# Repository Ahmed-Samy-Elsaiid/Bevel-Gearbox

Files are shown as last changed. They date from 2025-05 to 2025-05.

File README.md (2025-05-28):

# Bevel Gearbox Design Project

 


**A comprehensive design and analysis of a bevel gear transmission system developed for Mechanical Design II at Alexandria University.**

## 📌 Project Overview

This project presents a complete engineering solution for a bevel gear transmission system capable of:
- Transmitting **12.57 kW** power
- Converting **1200 rpm input** to **300 rpm output** (4:1 reduction ratio)
- Increasing torque from **100 N·m** to **400 N·m**
- Operating with **safety factors of 2.65** for both bending and contact stresses

## 🛠️ Technical Specifications

### ⚙️ Gear System
| Parameter | Pinion | Gear |
|---|---|---|
| Teeth Count | 15 | 60 |
| Pitch Diameter | 180 mm | 720 mm |
| Cone Angle | 14.04° | 75.96° |
| Module | 12 mm | 12 mm |
| Face Width | 100 mm | 100 mm |
| Pressure Angle | 20° | 20° |

### 🔩 Key Components
- **Bearings:** SKF 6210 (Dynamic load: 37.1kN, Static load: 23.2 kN)
- **Shafts:** 
  - Pinion shaft: Ø48-62mm
  - Gear shaft: Ø50-55mm
- **Seals:** Radial mechanical seals (Ø62mm)

## 📂 Repository Structure

```
Bevel-Gearbox
├── CAD
│   ├── Assembly                  # Main gearbox assembly and subassemblies
│   ├── Casing                    # Housing and structural components
│   ├── Gears                     # Bevel gear pair (pinion and wheel)
│   ├── Shafts                    # Rotating shaft components
│   ├── Keys                      # Keyways and power transmission keys
│   ├── Caps                      # Bearing caps and end covers
│   ├── Gaskets                   # Sealing interfaces
│   ├── Oil                       # Lubrication system components
│   ├── Sealing                   # Dynamic sealing elements
│   └── Drawing                   # Technical drawings (2D blueprints)
│
│── Calculations
│   └── Calculations.EES          # Engineering Equation Solver script
│
│── Documentation
│   └── Design Report.pdf         # Complete design report
│
└── README.md                     # Project documentation
```

## 🧑‍💻 Team Members

| Name                                      | 
|-------------------------------------------|
| Ahmed Samy Elsaiid Mohamed Ahmed Elshimy  | 
| Ahmed Saiid Abdelnaby Abdelrahman         |
| Ahmed Mohamed Ahmed Saleh                 | 
| Ahmed Mohamed Refaat Bassiouny            |
| Ayman Muhammad Hussien El-sayed Muhammed  | 
| Ziad Ashraf Mohamed Ali                   |
| Mohamed Ashraf Ali Mohamed                | 
| Mohamed Alaa Hassan Mabrouk               |
| Mahmoud Mohamed Abdallah Elnahas          |

## 🔍 Key Features

✅ **Precision Gear Design**  
- AGMA-compliant tooth profiles
- Optimal cone angles for perfect meshing
- 100mm face width for load distribution

✅ **Robust Mechanical Design**  
- SKF 6210 bearings for radial/axial loads
- Properly sized shafts (Von Mises criteria)
- Integrated sealing solutions

✅ **Complete Documentation**  
- 3D CAD models (SolidWorks)
- 2D manufacturing drawings (AutoCAD)
- Detailed stress analysis (AGMA standards)

## 📚 References

1. AGMA 2003-B97 - Bevel Gear Rating Standard
2. ISO 6336-1:2019 - Gear Load Capacity
3. SKF Bearing Catalogue (2022)
4. GearTrax by Camnetics

## 📄 License

Free for educational and non-commercial use. For commercial applications, please contact the author.

---

<div align="center">
  <i>Developed with ❤️ by Team 21 | Alexandria University | Mechanical Design II - Spring 2025</i>
</div>

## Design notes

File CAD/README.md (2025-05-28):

# Bevel Gearbox CAD Models



Complete CAD package for a bevel gearbox system. All files synchronized in the latest update.

## 🚀 Quick Start
1. **Download Bevel-Gearbox.zip**
2. Extract the archive
3. Open `Gear box assembly` in SolidWorks

## 📂 File Contents
| Folder | Contents |
|---|---|
| `Assembly`  | Main gearbox assembly |
| `Casing` | Housing and enclosure components  |
| `Gears` | Pinion and driven gear |
| `Shafts` | Input/output shafts |
| `Keys` | Shaft key components |
| `Caps` | End caps and covers |
| `Gaskets` | Sealing gaskets |
| `Oil` | Lubrication components |
| `Sealing` | Additional seals |
| `Drawing` | 2D technical drawings (DWG) |

## ⚠️ Important Notes
- **Requirements**: SolidWorks 2023 or compatible
- **All files updated**: 4 minutes ago
- **ZIP file contains**: Complete working assembly with all references
- **For collaborators**: Edit individual components before updating assemblies

## 🛠️ Troubleshooting
If files appear missing:
1. Always use the `Bevel-Gearbox.zip` package
2. In SolidWorks: Tools > Find References
3. Ensure all subfolders are in the same directory

## 📄 License

Free for educational and non-commercial use. For commercial applications, please contact the author.

---

<div align="center">
  <i>Developed with ❤️ by Team 21 | Alexandria University | Mechanical Design II - Spring 2025</i>
</div>

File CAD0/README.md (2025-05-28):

# Bevel Gearbox Design Project

 


A comprehensive design and analysis of a bevel gear transmission system developed for Mechanical Design II at Alexandria University.

## 📌 Project Overview

This project presents a complete engineering solution for a bevel gear transmission system capable of:
- Transmitting **12.57 kW** power
- Converting **1200 rpm input** to **300 rpm output** (4:1 reduction ratio)
- Increasing torque from **100 N·m** to **400 N·m**
- Operating with **safety factors of 2.65** for both bending and contact stresses

## 🛠️ Technical Specifications

### ⚙️ Gear System
| Parameter | Pinion | Gear |
|---|---|---|
| Teeth Count | 15 | 60 |
| Pitch Diameter | 180 mm | 720 mm |
| Cone Angle | 14.04° | 75.96° |
| Module | 12 mm | 12 mm |
| Face Width | 100 mm | 100 mm |
| Pressure Angle | 20° | 20° |

### 🔩 Key Components
- **Bearings:** SKF 6210 (Dynamic load: 37.1kN, Static load: 23.2 kN)
- **Shafts:** 
  - Pinion shaft: Ø48-62mm
  - Gear shaft: Ø50-55mm
- **Seals:** Radial mechanical seals (Ø62mm)

## 📂 Repository Structure

```
Bevel-Gearbox
│── Cad
│   ├── Assembly.SLDASM    # Complete gearbox assembly
│   ├── Pinion.SLDPRT      # Pinion 3D model
│   ├── Gear.SLDPRT        # Gear 3D model
│   └── Assembly.DWG       # 2D technical drawings
│
│── Calculations
│   └── EES_Code.EES       # Engineering Equation Solver script
│
│── Documentation
│   └── Project_Report.pdf # Complete design report
│
└── README.md              # Project documentation
```

## 🧑‍💻 Team Members

| Name                                      | 
|-------------------------------------------|
| Ahmed Samy Elsaiid Mohamed Ahmed Elshimy  | 
| Ahmed Saiid Abdelnaby Abdelrahman         |
| Ahmed Mohamed Ahmed Saleh                 | 
| Ahmed Mohamed Refaat Bassiouny            |
| Ayman Muhammad Hussien El-sayed Muhammed  | 
| Ziad Ashraf Mohamed Ali                   |
| Mohamed Ashraf Ali Mohamed                | 
| Mohamed Alaa Hassan Mabrouk               |
| Mahmoud Mohamed Abdallah Elnahas          |

## 🔍 Key Features

✅ **Precision Gear Design**  
- AGMA-compliant tooth profiles
- Optimal cone angles for perfect meshing
- 100mm face width for load distribution

✅ **Robust Mechanical Design**  
- SKF 6210 bearings for radial/axial loads
- Properly sized shafts (Von Mises criteria)
- Integrated sealing solutions

✅ **Complete Documentation**  
- 3D CAD models (SolidWorks)
- 2D manufacturing drawings (AutoCAD)
- Detailed stress analysis (AGMA standards)

## 📚 References

1. AGMA 2003-B97 - Bevel Gear Rating Standard
2. ISO 6336-1:2019 - Gear Load Capacity
3. SKF Bearing Catalogue (2022)
4. GearTrax by Camnetics

---

<div align="center">
  <i>Developed with ❤️ by Team 21 | Alexandria University | Mechanical Design II - Spring 2025</i>
</div>

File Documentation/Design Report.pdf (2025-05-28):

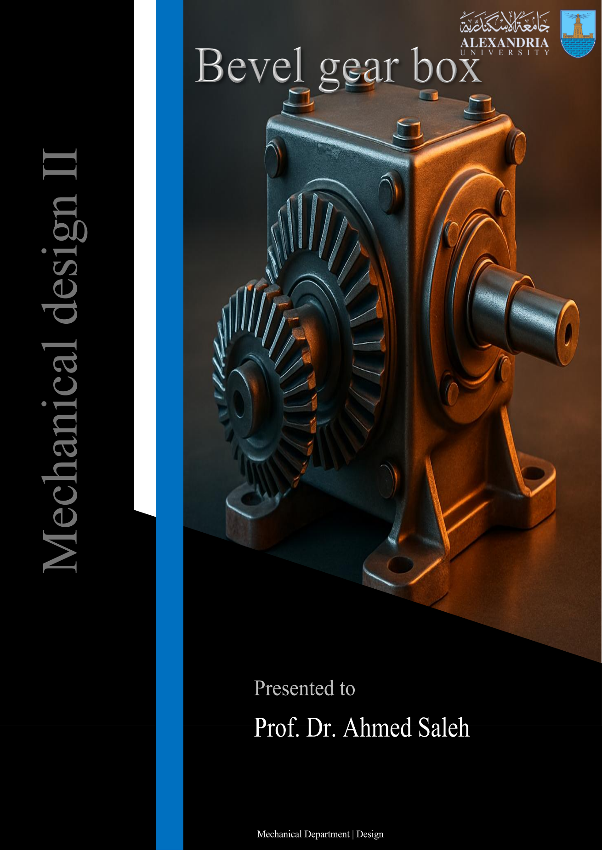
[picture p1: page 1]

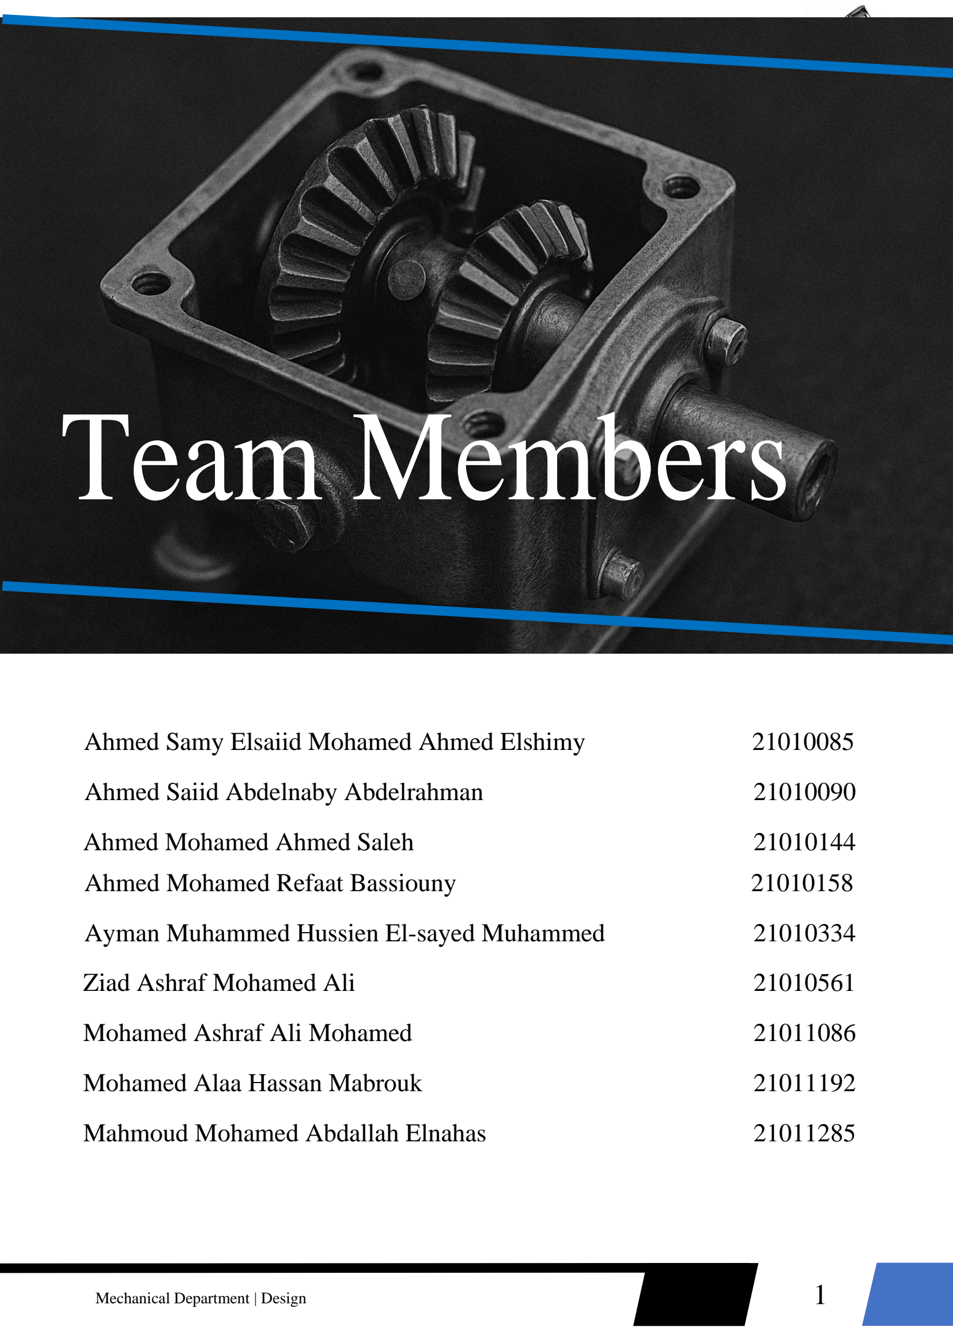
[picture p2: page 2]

Mechanical Department | Design
Ahmed Samy Elsaiid Mohamed Ahmed Elshimy | 21010085
Ahmed Saiid Abdelnaby Abdelrahman | 21010090
Ahmed Mohamed Ahmed Saleh | 21010144
Ahmed Mohamed Refaat Bassiouny | 21010158
Ayman Muhammed Hussien El-sayed Muhammed | 21010334
Ziad Ashraf Mohamed Ali | 21010561
Mohamed Ashraf Ali Mohamed | 21011086
Mohamed Alaa Hassan Mabrouk | 21011192
Mahmoud Mohamed Abdallah Elnahas | 21011285

# Team Members

# Contents

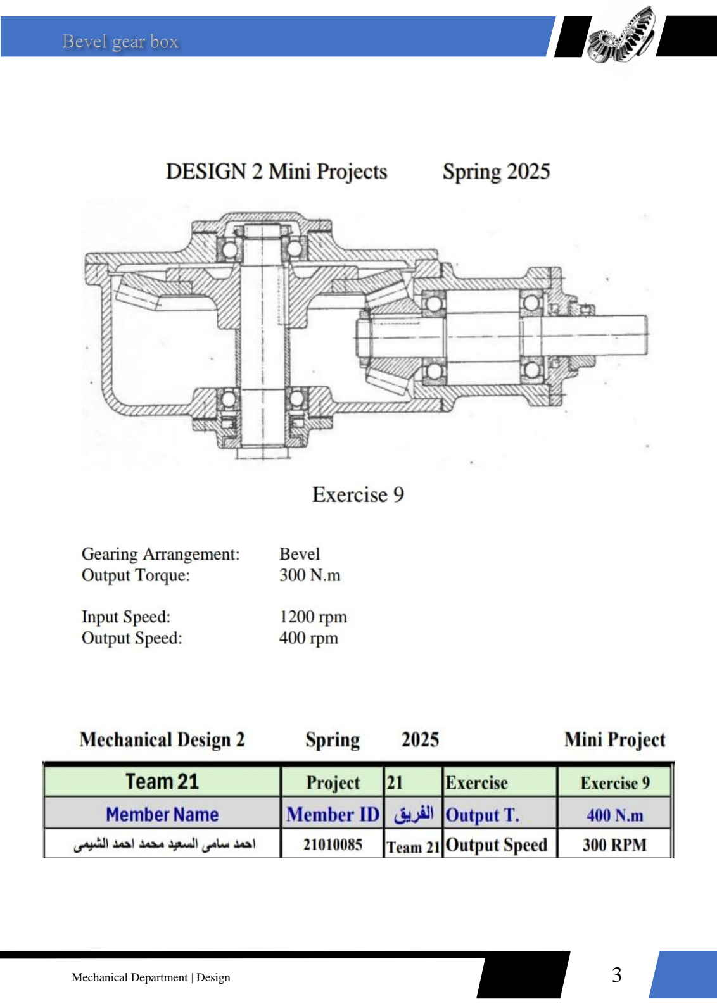
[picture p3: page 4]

## Abstract

This technical report presents a comprehensive design and engineering analysis of a bevel gear transmission system developed for efficient power transfer between intersecting shafts. The study focuses on creating an optimal gear pair configuration capable of transmitting 12.57 kW of power while converting an input speed of 1200 rpm (125.66 rad/s) to an output speed of 300 rpm (31.42 rad/s), with a corresponding torque increase from 100 N·m to 400 N·m through a 4:1 reduction ratio.

The research methodology incorporates a rigorous multi-stage engineering approach, beginning with fundamental kinematic calculations to verify speed and torque requirements. Detailed geometric design parameters are then established, including module selection (12 mm), tooth counts (15 teeth for pinion, 60 for gear), and precise pitch diameter determinations (180 mm and 720 mm respectively). The conical geometry of the bevel gears is carefully analyzed, with pinion and gear cone angles calculated at 14.04° and 75.96° to ensure proper meshing alignment.

A comprehensive force analysis forms a critical component of the study, systematically evaluating the three-dimensional loading conditions on the gear teeth. This includes calculation of tangential (1284.14 N), radial (453.43 N pinion/113.36 N gear), and axial (113.36 N pinion/453.43 N gear) force components, which are essential for subsequent shaft and bearing design considerations. The stress analysis employs American Gear Manufacturers Association (AGMA) standards to verify tooth strength under both bending and contact fatigue conditions, with particular attention to load distribution factors and dynamic effects.

The computer-aided design component utilizes industry-standard SolidWorks software for precise 3D modeling of all system components, including detailed gear tooth profiles and assembly relationships. Complementary 2D technical drawings produced in AutoCAD provide complete manufacturing specifications, incorporating geometric dimensioning and tolerancing (GD&T) standards. The integrated design approach ensures proper meshing characteristics while maintaining manufacturability requirements.

Results demonstrate a fully engineered bevel gear transmission system meeting all specified performance criteria while maintaining appropriate safety margins. The complete design package includes detailed gear geometry, force analysis data, and manufacturing documentation, providing a comprehensive solution for power transmission applications requiring shaft angle redirection. This study serves as a valuable reference for mechanical engineers designing similar bevel gear systems, offering both theoretical foundations and practical implementation guidance.

## Introduction

Bevel gears are fundamental components in mechanical power transmission systems where torque must be transferred between intersecting shafts, typically at 90 degrees. Their conical geometry allows efficient power transmission while accommodating angular misalignment. This report presents a comprehensive design and analysis of a bevel gear system based on specified operational requirements, including torque, speed, and power transmission efficiency.

## Objectives

The primary objectives of this study are:
1. To design a bevel gear pair with a 4:1 gear ratio, ensuring proper speed reduction from 1200 rpm (input) to 300 rpm (output) while increasing torque from 100 N·m to 400 N·m.
2. To perform force and stress analysis to validate gear tooth strength and durability.
3. To conduct shaft design calculations considering combined bending and torsional stresses.
4. To evaluate safety factors using AGMA (American Gear Manufacturers Association) standards for bending and contact stresses.

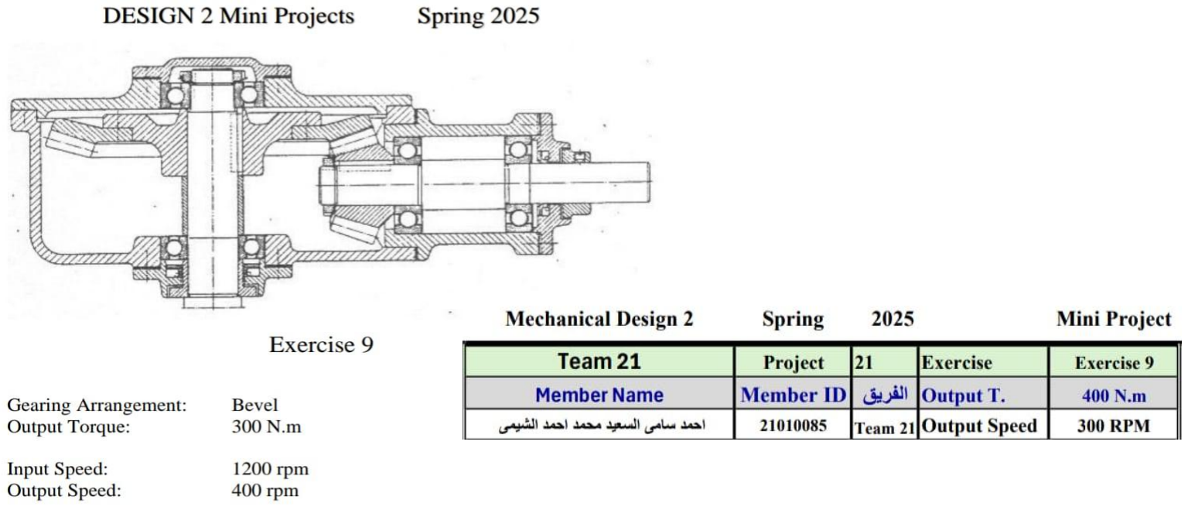
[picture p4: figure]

## Methodology

The design and analysis of the bevel gear transmission system followed a structured methodology, integrating theoretical calculations, computer-aided design (CAD), and validation techniques. The approach ensured a systematic evaluation of gear geometry, stress analysis, and manufacturability. The key stages of the methodology are outlined below.

## Design Calculations

The analytical phase involved determining critical parameters to meet performance requirements:
- Gear Ratio & Kinematics: Calculated input/output speeds and torque multiplication.
- Tooth Geometry: Determined module, pitch diameters, and cone angles based on AGMA standards.
- Force Analysis: Evaluated tangential, radial, and axial forces acting on gear teeth.
- Stress Analysis: Applied AGMA equations to assess bending and contact stresses.
- Safety Factors: Verified design reliability under operational loads.

## Computer-Aided Design (CAD)

The gear system was modeled using industry-standard CAD software to validate geometry and assembly:

- SolidWorks:
- Created 3D parametric models of the pinion and gear.
- Simulated gear meshing and interference checks.
- Generated technical drawings with tolerances and annotations.
- AutoCAD:
- Produced 2D manufacturing drawings with detailed sectional views.
- Specified key dimensions, surface finishes, and GD&T (Geometric Dimensioning & Tolerancing).

## Design Calculations

The design process follows a systematic approach:

1. Kinematic Analysis: Calculation of gear ratio, angular velocities, and power transmission.
2. Geometric Design: Determination of module, pitch diameters, and tooth geometry.
3. Force Analysis: Computation of tangential, radial, and axial forces acting on gear teeth.
4. Stress Analysis: Application of AGMA equations to assess bending and contact stresses.
5. Shaft Design: Determination of minimum shaft diameter based on combined loading conditions.

## Kinematic and Power Analysis

The power transmission system operates under the following conditions:

Parameter | Pinion | Gear
Speed (rpm) | 1200 | 300
Angular velocity (rad/s) | 125.66 | 31.42
Torque (N·m) | 100 | 400
Power (kW) | 12.566 | 12.566

The power transmission remains constant (neglecting losses), satisfying the fundamental relationship: P = T × ω = Constant
where:
- P = Power (W)
- T = Torque (N · m)
- ω = Angular velocity (rad/s)

## Geometric Design Specifications

Gear Parameters

Design Parameter | Value
Gear ratio (mG) | 04:01
Module (m) | 12 mm
Pinion teeth (Np) | 15
Gear teeth (Ng) | 60
Pressure angle (φ) | 20°
Face width (b) | 100 mm

Pitch Geometry

1. Pinion Pitch Diameter (dₚ): dp = Np × m = 15 × 12 = 180 mm
2. Gear Pitch Diameter (dg): dg = Ng × m = 60 × 12 = 720 mm
3. Pinion Cone Angle (γₚ): γp = tan⁻¹
(

Ng
Np

) = tan − 1(6015) = 14.04°

4. Gear Cone Angle (γg):
γg = 90° − γp = 90° − 14.04° = 75.96°
5. Average Diameter (dₐᵥ):
- For pinion:
davpinion = dp − b ∗ cosγp = 180 − 100 ∗ cos(14.04°) = 155.75 mm
- For gear:
davgear = dg − b ∗ cosγg = 720 − 100 ∗ cos(75.96°) = 622.99 mm

## Force Analysis

The forces acting on the gear teeth are critical for shaft and bearing design:

Force Component | Pinion (N) | Gear (N)
Tangential (Wt ) | 1284.14 | 1284.14
Radial (Wr ) | 453.43 | 113.36
Axial (Wa) | 113.36 | 453.43

Force Equations

- Tangential Force:
Wt = dav ∗ 2T
- Radial Force:
Wr = Wt
∗ tanφ ∗ cosγ
- Axial Force:
Wa = Wt
∗ tanφ ∗ sinγ

## AGMA Stress Analysis

Bending Stress (σF)
σF = bmWt

KAKv

′YxKH

YBYJ1
Where:
- KA = 1.35 (Ligℎt sℎock)
- Kv

′ = 1.5 (Quality factor Qv = 7)
- Yx = 0.5868 (Size factor)
- KH = 1.156 (Load distribution factor)
- YJ = 0.23 (Geometry factor)

Contact Stress (σH)

σH = ZE (

Wt
bdpZL

KAKv

′ZxZxc)

1
2

Where:
- ZE = 190MPa (Steel)
- Zx = 0.9295 (Mesℎ alignment factor)

Safety Factors
- Bending Safety Factor (SF):
SF =

σF

σFP
- Contact Safety Factor (SH): SH =

σH

σHP

## Shaft Design

The shaft must withstand combined bending and torsional stresses. Using von Mises theory:

d

3 =

16

π τall √(Kb Mb +
αFad
8

)

2
+ (Kt Mt

)

2

Where:

- τall = 47.5 Mpa
- Kb = 2 & Kt = 1.5

## Bearing Selection

Once the shaft design was finalized and the reaction forces at each bearing location were calculated, the next step was to select suitable bearings that can withstand the applied radial and axial loads while ensuring reliability and longevity.
The primary criteria for bearing selection included:
a. Load carrying capacity (both radial and axial),
b. Rotational speed,
c. Operating life,
d. Ease of installation and availability.

Based on the calculated reaction forces at the shaft supports (as shown in the previous section), and considering the moderate speed and load conditions in our application, we chose to use deep groove ball bearings, which are well-suited for handling radial loads and moderate axial loads with relatively low friction.
Selected Bearing: SKF 6210
We selected the SKF 6210 bearing for both the pinion and gear shafts. This offers the following advantages:
- High radial load capacity, which matches the calculated forces in our system,
- Moderate axial load capability, suitable for the axial components generated by the bevel gear interaction,
- Rated for high-speed applications, aligning with our gearbox’s operating conditions,
- Standard dimensions, making it easy to integrate into our shaft design.
- SKF 6210 specifications:
- Bore diameter: 50 mm
- Outside diameter: 90 mm
- Width: 20 mm
- Dynamic load rating (C): 37.1kN
- Static load rating (C₀): 23.2 kN
- Maximum speed: up to 7,500 rpm (depending on lubrication)

This bearing was chosen for its balance between load capacity, speed, and availability, ensuring reliable performance in our gearbox design.

The following script is written in Engineering Equation Solver (EES) and is used to analyze and design a bevel gear transmission system. The code defines all relevant input parameters, assumptions, and material properties, and performs detailed calculations for gear geometry, tangential loads, AGMA-based bending and wear stress analysis, shaft torque and moment evaluation, shaft diameter sizing under combined loading, and bearing reaction forces. The solution is automated using EES to ensure accuracy, flexibility in parameter variation, and to support design decisions in accordance with standard mechanical design practices.

## EES Code

{Givens}

T_out = 400
N_in = 1200 / 60
N_out = 300 / 60

{Assumptions}

b = 100

S_F = 2.65
S_H = 2.65
m = 12
n_p = 15
n_g = 4 * n_p
H_p = 240
H_g = 200
phi = 20
gamma = arctan(n_g / n_p)
L_p = 10 ^ 8
L_g = L_p / 4

{Precalculations}

d_p = m * n_p
d_g = m * n_g
P_w = T_out * N_out * 2 * pi
v = pi * d_p * N_in /1000
W|t = P_w / v
d_av_p = d_p - b * cos(gamma) d_av_g = d_g - b * sin(gamma)

{Bending based}

k_a = 1
k_v = 1.3
Y_x = 0.4867 + 0.008339 * m k_mb = 1.1
k_H = k_mb + 5.6 * b ^ 2 * 10 ^ (-6) Y_b = 1
Y_j_p = 0.24
Y_j_g = 0.18
sigma_F_p = W|t * k_a * k_v * y_x * k_h / (b * m * Y_b * Y_j_p) sigma_F_g = W|t * k_a * k_v * y_x * k_h / (b * m * Y_b * Y_j_g) sigma_F_lim_p = 0.3 * H_p + 14.48
sigma_F_lim_g = 0.3 * H_g + 14.48
Y_NT_p = 1.3558 * L_P ^ (-0.0178)

Y_NT_g = 1.3558 * L_g ^ (-0.0178)
K_theta = 1
Y_z = 1
sigma_FP_P = sigma_F_lim_p * Y_NT_p / (K_theta * Y_z) sigma_FP_g = sigma_F_lim_g * Y_NT_g / (K_theta * Y_z)

{S_F = sigma_FP_g / sigma_F_g}
{S_F = sigma_FP_p / sigma_F_p}

S_F_p = sigma_FP_g / sigma_F_g S_F_g = sigma_FP_p / sigma_F_p

{Wear based}

Z_E = 190
Z_x = 0.00492 * b + 0.4375
Z_xc = 2
Z_i = 0.078
sigma_H = Z_E * (W|t * k_a * k_v * k_h * z_x * z_xc / (b * d_p * z_i)) ^ (0.5) sigma_H_lim_p = 2.35 * H_p + 162.89
sigma_H_lim_g = 2.35 * H_g + 162.89
Z_NT_p = 3.4822 * L_p ^ (-0.0602)
Z_NT_g = 3.4822 * L_g ^ (-0.0602) Z_w_p = 1
Z_w_g = 1.01
K_z = Y_z
sigma_HP_P = sigma_H_lim_p * Z_NT_p * Z_W_p / (K_theta * k_z) sigma_HP_g = sigma_H_lim_g * Z_NT_g * Z_w_g / (K_theta * k_z)

{S_H = sigma_HP_P / sigma_H}
{S_H = sigma_HP_g / sigma_H}

S_H_p = sigma_HP_P / sigma_H
S_H_g = sigma_HP_g / sigma_H

{Forces, torques, and moments on pinion}

F_t_p = W|t * d_p / d_av_p
F_a_p = F_t_p * tan(phi) * cos (gamma) F_r_p = F_t_p * tan(phi) * sin (gamma) F_tr_p = (F_t_p ^ 2 + F_r_p ^2 ) ^ (0.5) L_tr_p = 70 + 20
M_t_p = (F_t_p + W_p) * L_tr_p M_a_p = F_a_p * d_av_p / 2
M_r_p = F_r_p * L_tr_p
M_ra_p = M_r_p - M_a_p
M_p = (M_t_p ^ 2 + M_ra_p ^2) ^ (0.5) T_p = F_t_p * d_av_p / 2

{Bearing reactions for pinion shaft}

L_B_p = 100
W_p = 17 *9.81
B_n_t_p = (F_t_p + W_p) * (L_tr_p + L_B_p) / L_B_p B_n_a_p = M_a_p / L_B_p
B_n_r_p = F_r_p * (L_tr_p + L_B_p) / L_B_p B_n_ra_p = B_n_r_p - B_n_a_p
B_n_p = (B_n_t_p ^ 2 + B_n_ra_p ^2) ^ (0.5) B_f_p = M_p / L_B_p

{Shaft design for pinion}

k_b = 1.5
k_t = 1
S_y = 380
{F_s_p = 3}
d_sh_p = 48
d_sh_u_p = d_sh_p - 1
tau_all_p = S_y * 0.75 *0.5 / F_s_p
alpha_p = 1 / (1 - 0.0044 * (4 * (L_tr_p + L_B_p) / d_sh_u_p))
d_sh_u_p = (16 / (pi * tau_all_p) * ((k_b * M_p + alpha_p * f_a_p * d_sh_u_p / 8) ^ 2 + (k_t * T_p) ^ 2) ^ (0.5)) ^ (1 / 3)

{Forces, torques, and moments on gear}

F_t_g = F_t_p
F_a_g = F_r_p
F_r_g = F_a_p
L_tr_g = 80 + 20
F_tr_g = (F_t_g ^ 2 + F_r_g ^2 ) ^ (0.5) M_t_g = F_t_g * L_tr_g
M_a_g = F_a_g * d_av_g / 2
M_r_g = F_r_g * L_tr_g
M_ra_g = M_r_g - M_a_g
M_g = B_f_g * (L_B_g - L_tr_g) T_g = T_p * N_g / N_p

{Bearing reactions for gear shaft}

L_B_g = 300
w_gk = (103 + 27.5) * 9.81
B_n_t_g = (F_t_g + W_gk) * (L_B_g - L_tr_g) / L_B_g B_n_a_g = M_a_g / L_B_g
B_n_r_g = F_r_g * (L_B_g - L_tr_g) / L_B_g B_n_ra_g = B_n_r_g - B_n_a_g
B_n_g = (B_n_t_g ^ 2 + B_n_ra_g ^2) ^ (0.5) B_f_t_g = (F_t_g + W_gk) * (L_tr_g) / L_B_g B_f_a_g = M_a_g / L_B_g
B_f_r_g = F_r_g * (L_tr_g) / L_B_g B_f_ra_g = B_f_r_g + B_f_a_g

B_f_g = (B_f_t_g ^ 2 + B_f_ra_g ^2) ^ (0.5)

{Shaft design for gear}

{F_s_g = 3}
d_sh_g = 62
tau_all_g = S_y * 0.75 *0.5 / F_s_g
alpha_g = 1 / (1 - 0.0044 * (4 * (L_tr_g + L_B_g) / d_sh_g))
d_sh_g = (16 / (pi * tau_all_g) * ((k_b * M_g + alpha_g * f_a_g * d_sh_g / 8) ^ 2 + (k_t * T_g) ^ 2) ^ (0.5)) ^ (1 / 3)

{Bearing selection}

{basic static load}
{Fa/Fr<0.8 ... Xo=1,Yo=0}

xo=1
yo=0

{normal condition}

Fs=1.2
Po= xo*B_n_p + yo*F_a_p
Co= Fs*Po

{SKF 6210, co=23.2, c=37.1} {basic dynamic load}
{fo*Fa/co=0.1104 < e=0.17932}

x=1
y=0
{uniform load}
Ks=1
{inner ring rotation}
vo=1
{basic rating life}
L=360
P=x*vo*B_n_p+y*F_a_p
C=Ks*P*(L)^(1/3)

## Computer-Aided Design (CAD)

After completing the analytical calculations and determining the required forces, torques, and dimensions for the system components, we proceeded to the mechanical design phase. This phase is essential for transforming theoretical data into a functional and manufacturable 3D model.
Using SolidWorks, we modeled each individual part of the system with precise dimensions derived from our calculations. The design ensures mechanical compatibility, proper alignment, and load distribution among gears, shafts, and bearings.
In the following section, each part is presented with its:
- Name
- Dimensions
- Material
- Function in the assembly

This step bridges the gap between theoretical engineering principles and practical implementation, ensuring that each component meets the mechanical and operational requirements of the system.

## Gear Modeling Using GearTrax

To ensure high accuracy and compliance with gear design standards, the bevel gears were modeled using GearTrax by Camnetics, a specialized add-in for SolidWorks. This tool provides a robust and precise method for generating 3D gear geometry based on input parameters such as:

- Number of teeth
- Pressure angle
- Module or diametral pitch
- Gear ratio
- Shaft angle (typically 90° for bevel gears)

Using GearTrax allowed us to automatically generate the correct tooth profile and gear geometry according to AGMA standards, which significantly improved the quality and reliability of the gear design. The resulting models were seamlessly integrated into the SolidWorks assembly, ensuring accurate alignment and meshing between the pinion and the driven gear.
This approach minimized manual modeling errors and accelerated the design process while maintaining mechanical accuracy and consistency.

### Gear 1 (Pinion):

- Number of teeth: 15
- Pitch diameter: 180 mm
- Pressure angle: 20°
- Cone Angle (γ): 14.04°
- Face width: 100mm

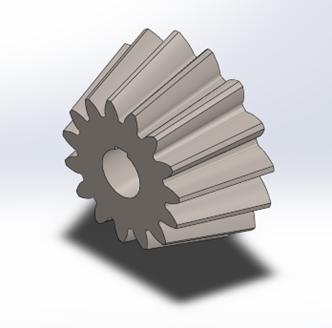
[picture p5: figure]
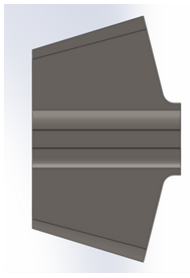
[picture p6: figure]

### Gear 2 (Gear):

- Number of teeth: 60
- Pitch diameter: 720 mm
- Pressure angle: 20°
- Cone Angle (γ): 75.96°
- Face width: 100mm

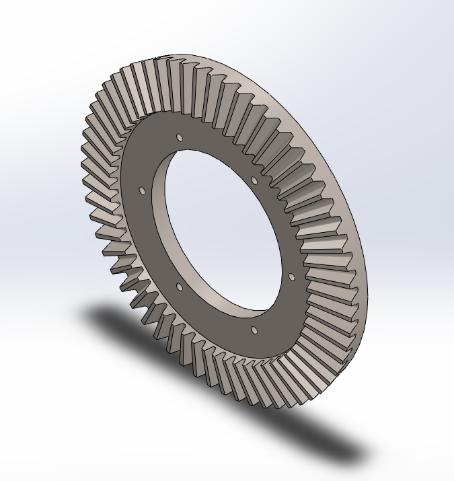
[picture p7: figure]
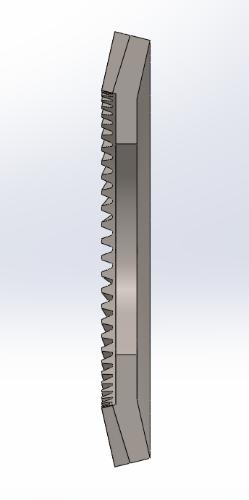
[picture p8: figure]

## Gasket Set for Bevel Gearbox Assembly

To ensure effective sealing and maintain pressure integrity within the gearbox, four custom-designed flat gaskets were modeled and integrated into the assembly. These gaskets serve to prevent lubricant leakage and protect internal components from external contaminants. All gaskets were designed in accordance with the mating flange profiles in SolidWorks, using precise cutout geometry and bolt hole alignment for seamless installation. Manufactured from 3 mm thick compressed fiber material, they offer high resistance to oil, temperature, and mechanical deformation, making them ideal for use in gear-driven power transmission systems.

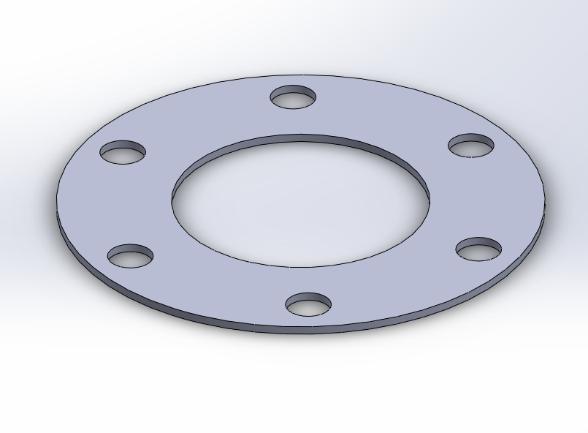
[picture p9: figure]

Gasket 1:
- Use: Sealing interface between shaft housing, gearbox casing (inlet and outlet sides) and sealing interface for the shaft support flange
- Dimensions:
- Outer diameter: 170 mm
- Inner cutout: 90 mm
- Thickness: 3 mm
- Bolt PCD: 140 mm
- Quantity: 3 identical gaskets (inlet + outlet)

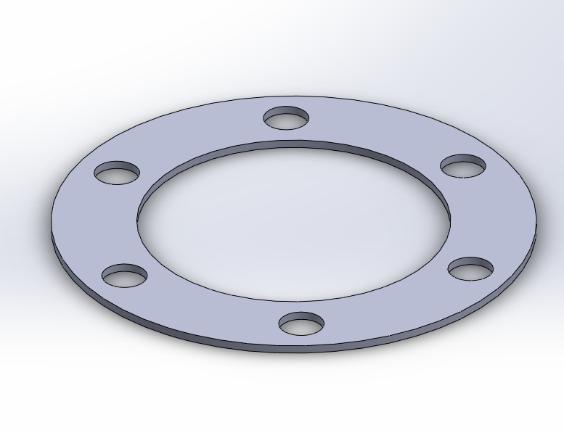
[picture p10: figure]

Gasket 2:
- Use: Between small support case and gearbox wall
- Dimensions:
- Outer diameter: 170 mm
- Inner cutout: 110 mm
- Thickness: 3 mm
- Bolt PCD: 140 mm

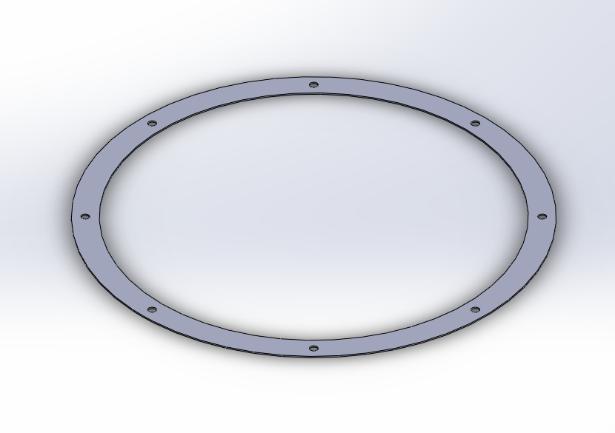
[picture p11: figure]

Gasket 3:
- Use: Sealing between the main gearbox housing and support structure
- Dimensions:
- Outer diameter: 870 mm
- Inner cutout: 770 mm
- Thickness: 3 mm
- Bolt PCD: 820 mm

## Cap Components for Bevel Gearbox Assembly

To ensure proper enclosure, shaft alignment, and mechanical protection, three distinct cap configurations were integrated into the bevel gearbox assembly. Each cap was modeled in SolidWorks with precision bolt patterns and center bore profiles to ensure compatibility with mating shafts, housings, and gaskets. The designs incorporate flat-faced surfaces and mounting flanges, simplifying installation and minimizing vibration-induced wear. All caps are assumed to be manufactured from mild steel unless otherwise specified, offering excellent machinability and structural integrity.

Cap 1:
- Function: Fully encloses the large side of the gearbox casing
- Dimensions:
- Outer diameter: 870 mm
- Boss height: 90 mm
- Pitch Circle Diameter (PCD): 820 mm
- Features: Includes a central hub with through-hole for optional alignment pin or shaft stub, and bolt holes along the outer edge for secure sealing
- Mounted with: Gasket (870×770×3, PCD: 820 mm)

Cap 2:

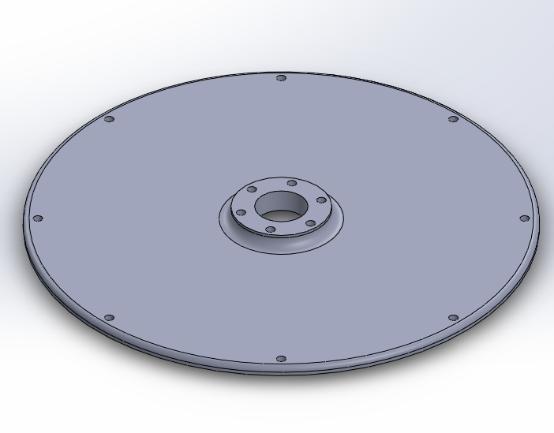
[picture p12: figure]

- Function: Closes and centers the shaft inlet region while allowing shaft clearance
- Dimensions:
- Outer diameter: 170 mm
- Boss height: 0 mm
- Pitch Circle Diameter (PCD): 140 mm
- Features: Flat design for flush mounting against shaft inlet housing; central hole accommodates shaft passage
- Mounted with: Gasket (170×90×3, PCD: 140 mm)

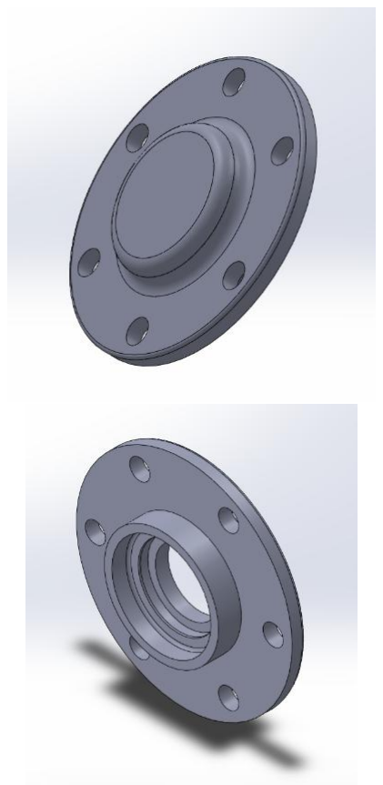
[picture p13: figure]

Cap 3:
- Function: Closes and centers the shaft outlet while providing axial spacing
- Dimensions:
- Outer diameter: 170 mm
- Boss height: 50.1 mm
- Pitch Circle Diameter (PCD): 140 mm
- Features: Raised boss ensures proper axial positioning and alignment for the output shaft; bolt holes are evenly spaced for stable fastening
- Mounted with: Gasket (170×90×3, PCD: 140 mm)

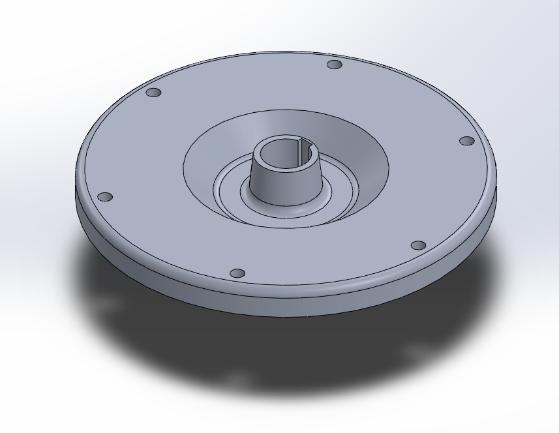
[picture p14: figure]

## Gear Mounting Kit

- Function: Secures the pinion to the input shaft with anti-rotation and axial retention.
- Dimensions:
- Outer diameter:450 mm
- Boss height: 50 mm
- Pitch Circle Diameter (PCD): 400 mm

## Gearbox Cases (Housings) – General Overview

Gearbox cases (or housings) are structural enclosures that serve as the foundation for gear systems, providing:
1. Alignment: Precise positioning of gears, shafts, and bearings.
2. Protection: Shielding internal components from contaminants (dust, moisture) and mechanical damage.
3. Lubrication Management: Contain oil/grease and facilitate cooling.
4. Load Distribution: Absorb and transmit operational forces (torque, vibrations).

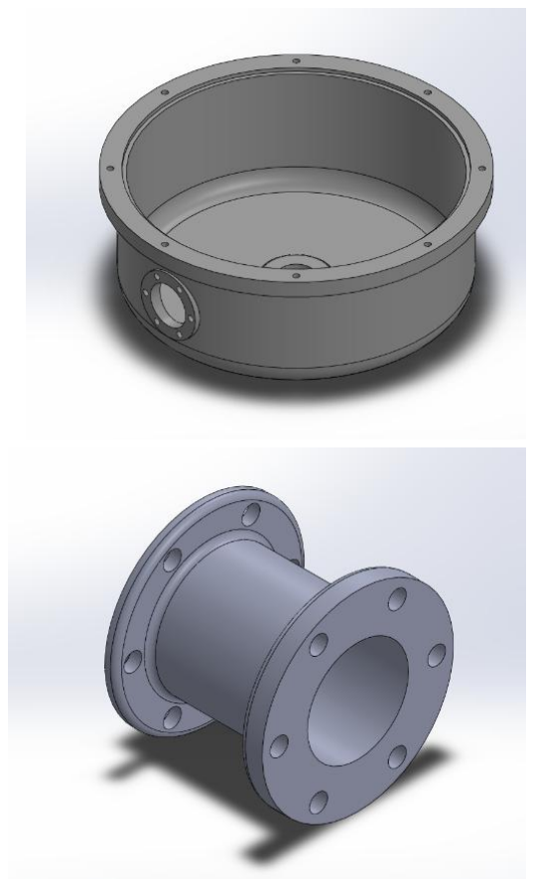
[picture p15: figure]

Big Case
- Function: The main housing encloses and
supports the large bevel gear and output shaft, providing structural rigidity, bearing alignment, and lubrication containment while handling high torque and radial loads.
- Dimensions:
- Outer diameter: 870 mm
- Boss height: 750 mm
- Pitch Circle Diameter (PCD): 820 mm

Small Case
- Function: The pinion housing secures and aligns the input shaft and bearings, ensuring precise gear meshing and sealing against lubricant leaks and contaminants.
- Dimensions:
- Outer diameter: 170 mm
- Boss height: 90 mm
- Pitch Circle Diameter (PCD): 140 mm

## Keys

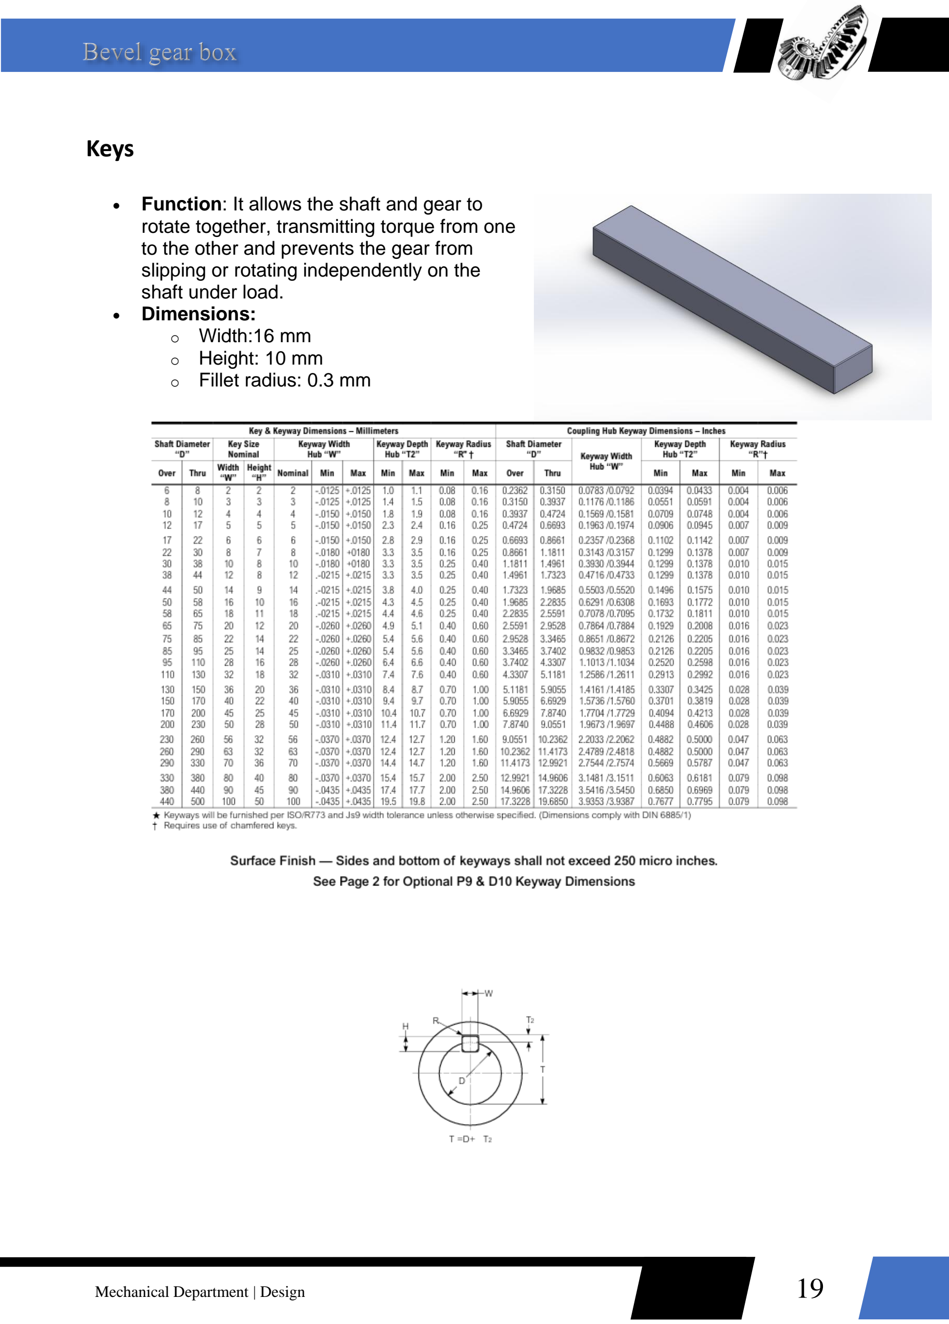
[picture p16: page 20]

- Function: It allows the shaft and gear to rotate together, transmitting torque from one to the other and prevents the gear from slipping or rotating independently on the shaft under load.
- Dimensions:
- Width:16 mm
- Height: 10 mm
- Fillet radius: 0.3 mm

## Radial Sealing

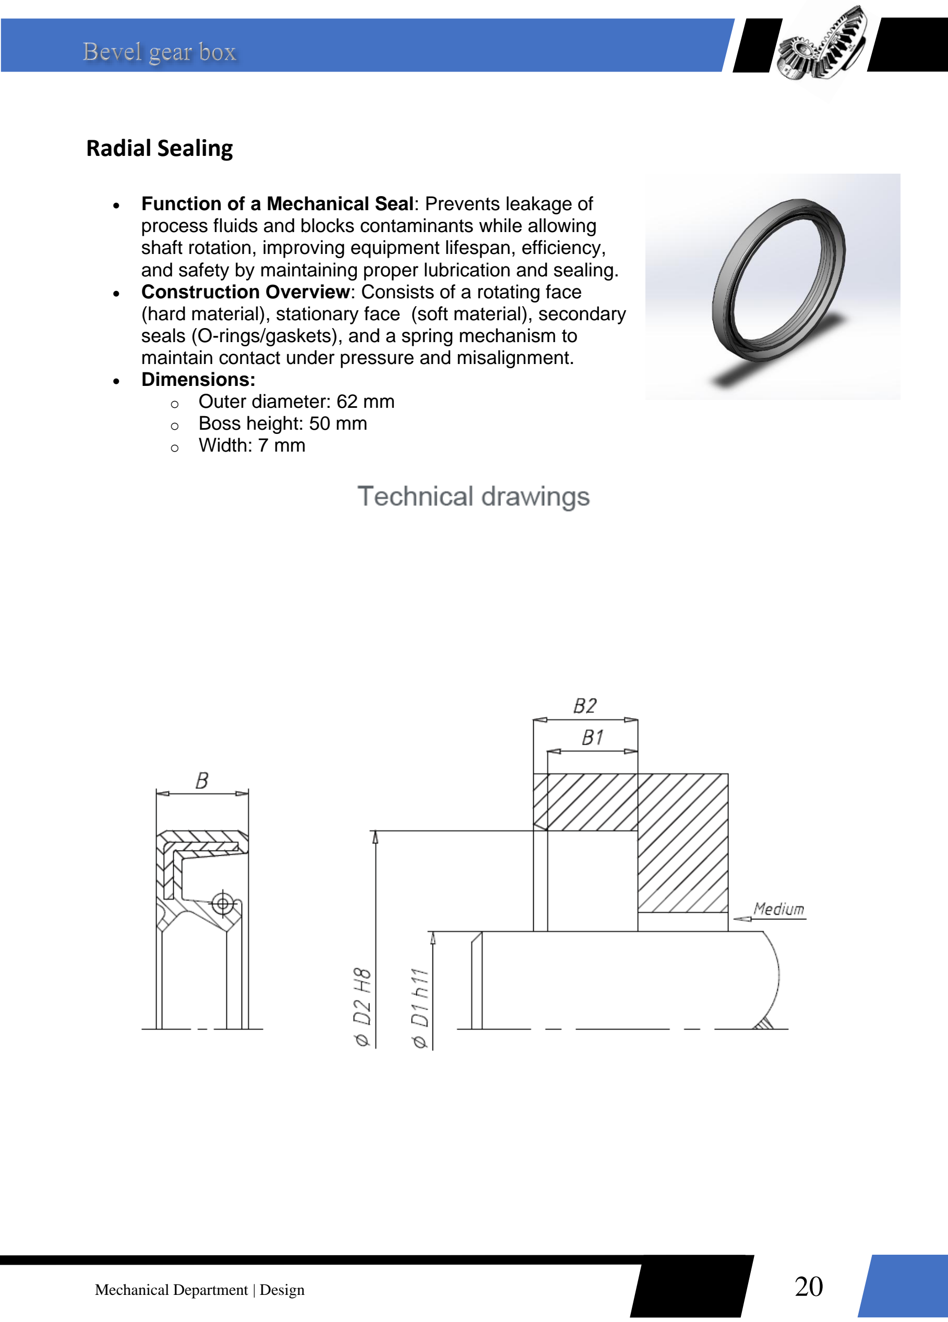
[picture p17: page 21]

- Function of a Mechanical Seal: Prevents leakage of process fluids and blocks contaminants while allowing shaft rotation, improving equipment lifespan, efficiency, and safety by maintaining proper lubrication and sealing.
- Construction Overview: Consists of a rotating face (hard material), stationary face (soft material), secondary seals (O-rings/gaskets), and a spring mechanism to maintain contact under pressure and misalignment.
- Dimensions:
- Outer diameter: 62 mm
- Boss height: 50 mm
- Width: 7 mm

## Shafts

The shaft serves as the backbone of mechanical systems, primarily transmitting torque and rotational motion between components like motors, gears, and couplings. It provides a mounting surface for critical elements such as bearings, pulleys, and seals, with features like keyways ensuring secure torque transfer via keys. Designed to withstand bending and torsional stresses, the shaft’s stepped shoulders and grooves facilitate precise bearing placement for axial and radial support, while its dimensions (diameter, length, and tolerances) dictate load capacity, alignment, and compatibility with mating parts.

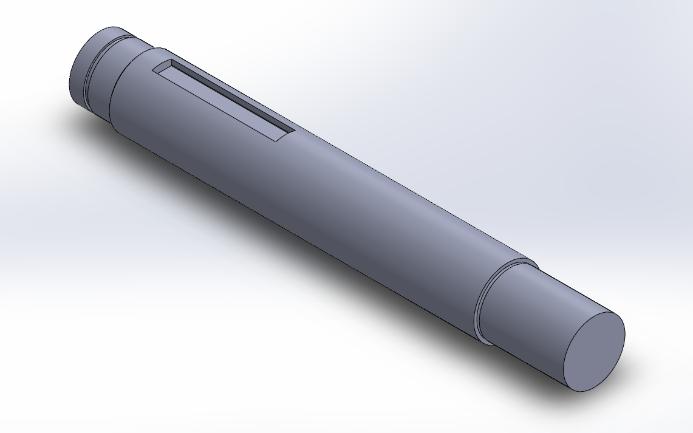
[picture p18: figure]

Gear shaft:

- Function: Drive the motion to the gear.
- Dimensions:
- Minor diameter: 50 mm
- Major diameter: 55 mm

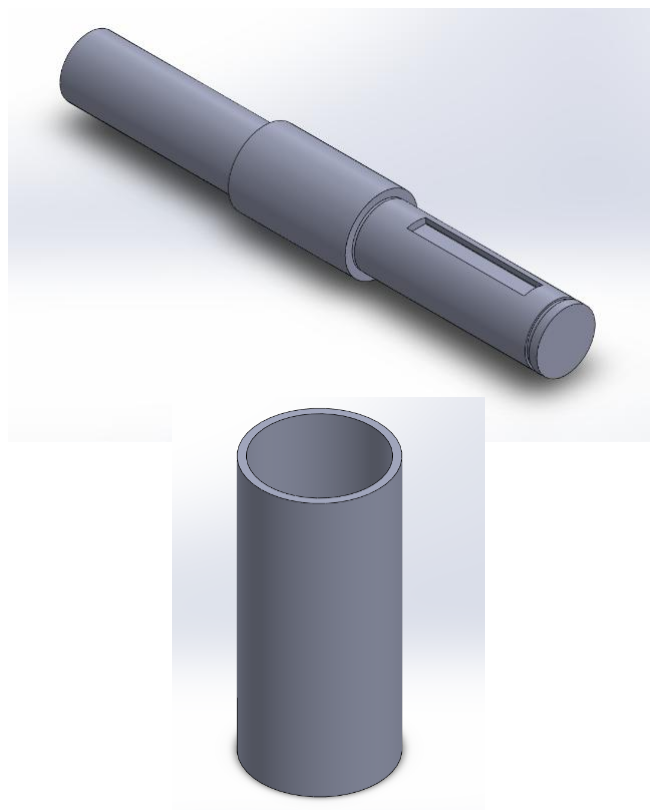
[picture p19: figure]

Pinion shaft:

- Function: Transmit the motion to the Pinion.
- Dimensions:
- Minor diameter: 50 mm
- Major diameter: 62 mm

Collar:

- Function: Support the gear kit.
- Dimensions:
- Outer diameter: 55 mm
- Inner diameter: 62 mm
- Height: 135mm

## Selection

Gears:

Gear | Face width | Gear diameter | Pinion diameter
Calculated | 74.39 | 720 | 180
Used | 100 | 720 | 180

Bearings:

## 4 Bearings SKF 6210

Bearing | Basic dynamic load | Basic static load
Calculated | 20368 | 3436
Used | 37100 | 23200

Shafts:

Shafts | Pinion | Gear
Calculated | 29.92 | 37.72
Used | 48 | 62

## Conclusion

This comprehensive study successfully designed and analyzed a bevel gear transmission
system capable of transmitting 12.57 kW at a 4:1 reduction ratio, converting 1200 rpm (125.66 rad/s) input to 300 rpm (31.42 rad/s) output while increasing torque from 100 N·m to 400 N·m. Through kinematic, geometric, and stress analyses, the system was optimized for strength, durability, and manufacturability in compliance with AGMA standards.
Key achievements include:
- Precision gear design (module 12 mm, 15/60 teeth) with proper cone angles (14.04° & 75.96°) for optimal meshing.
- Force and stress validation, ensuring safety factors (S_F = 2.65, S_H = 2.65) under bending and contact fatigue.
- Shaft and bearing selection (e.g., SKF 6210) to withstand combined radial/axial loads.
- 3D CAD modeling (SolidWorks, GearTrax) and 2D manufacturing drawings (AutoCAD) for seamless production.
- Integrated sealing solutions (gaskets, mechanical seals) to prevent leaks and contamination.

The final design meets all performance, reliability, and safety requirements, providing a robust reference for similar bevel gear applications. Future work could explore dynamic
simulations or prototype testing for further validation.

## References

1. American Gear Manufacturers Association (AGMA). (2015). *AGMA 2003-B97: Rating the Pitting Resistance and Bending Strength of Generated Straight Bevel, Zerol Bevel, and Spiral Bevel Gear Teeth*. AGMA.
2. ISO. (2019). *ISO 6336-1:2019: Calculation of load capacity of spur and helical gears — Part 1: Basic principles, introduction and general influence factors*. International Organization for Standardization.
3. Klingelnberg, J. (2016). Bevel Gear: Fundamentals and Applications. Springer. (Covers bevel gear geometry, manufacturing, and load analysis)
4. Maitra, G. M. (1994). Handbook of Gear Design (2nd ed.). Tata McGraw-Hill. (Classic reference for gear theory, stress calculations, and design rules)
5. SKF Group. (2022). SKF Bearing Catalogue: Radial Ball Bearings.
(For SKF 6210 bearing specifications; include URL if accessed online)
6. Camnetics. (2023). GearTrax User Manual: Bevel Gear Design Module. (Cite as software/documentation; add version number if available)

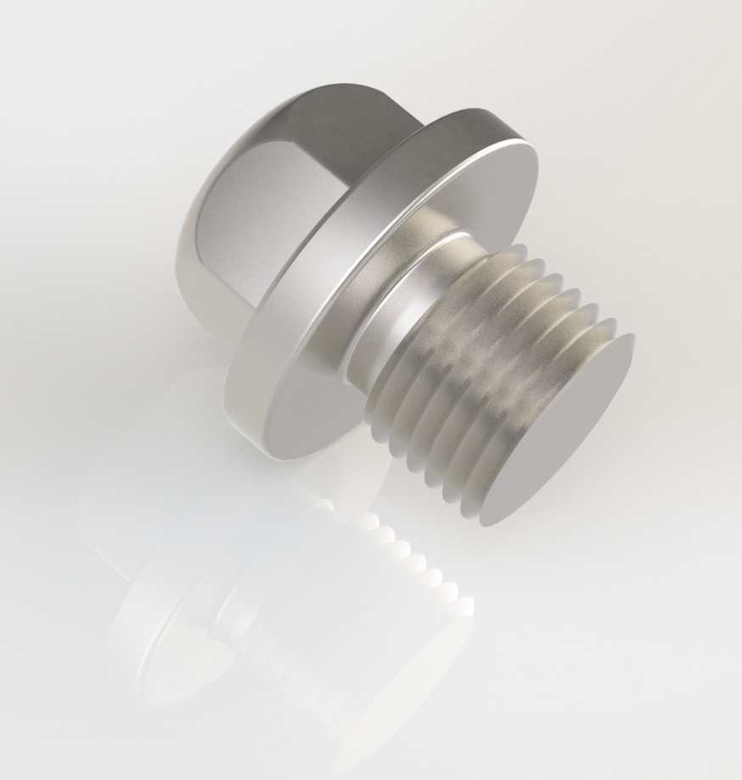
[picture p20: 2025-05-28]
CAD/Oil/Oil Plug Render.jpg

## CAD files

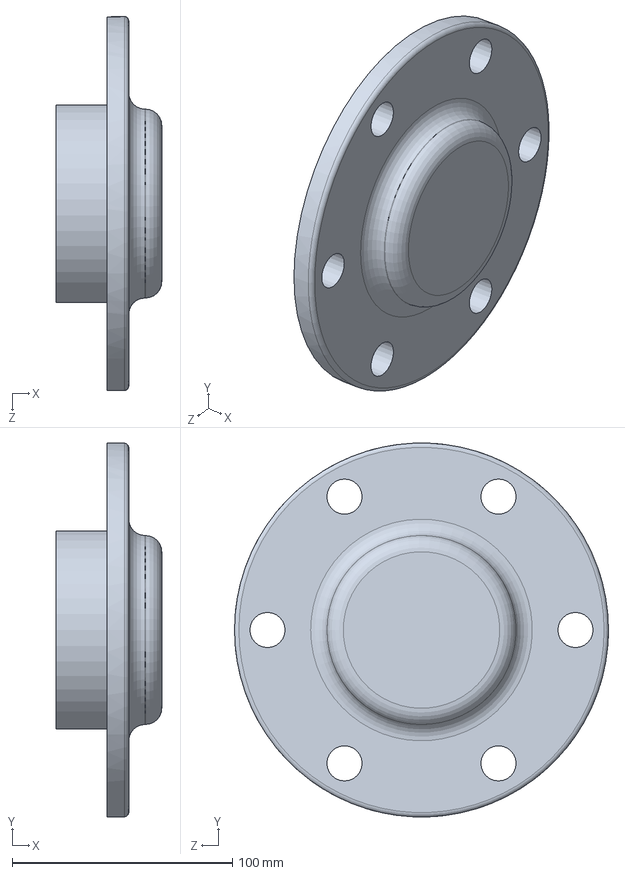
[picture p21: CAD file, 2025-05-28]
CAD/Caps/Cap close.SLDPRT
48.0 x 169.9 x 170.0 mm

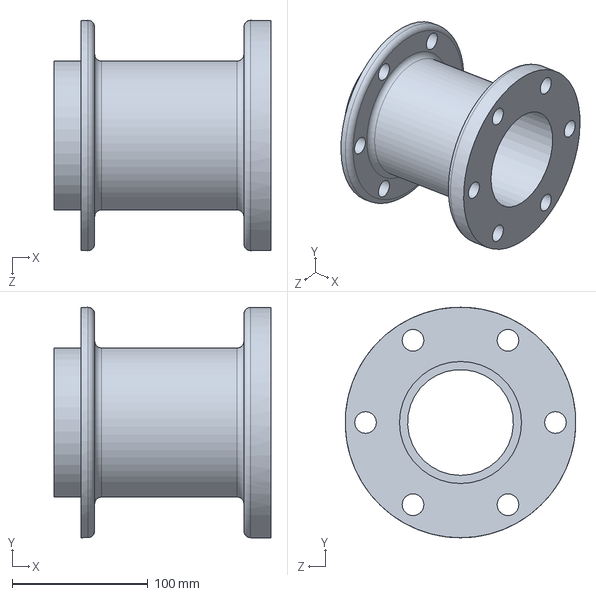
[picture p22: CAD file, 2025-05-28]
CAD/Casing/small case.SLDPRT
160.0 x 170.0 x 170.0 mm

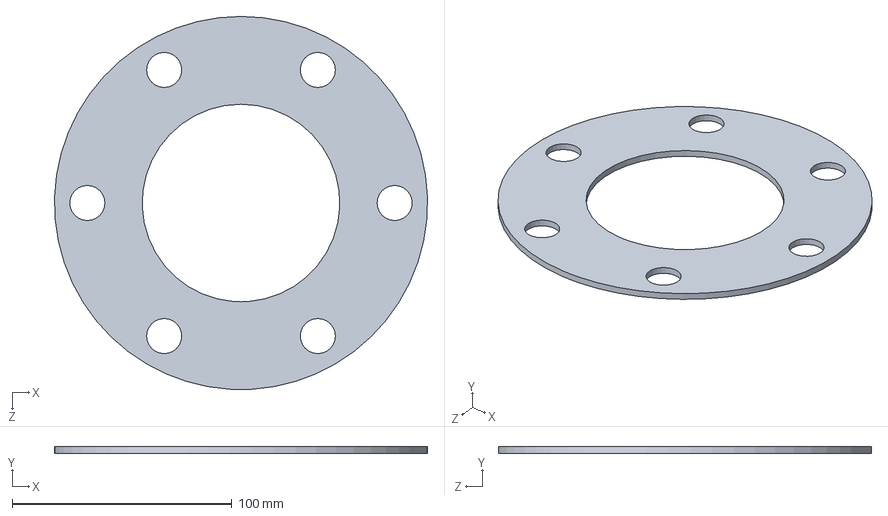
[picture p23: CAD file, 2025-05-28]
CAD/Gaskets/Gasket close cap.SLDPRT
169.9 x 3.00 x 170.0 mm

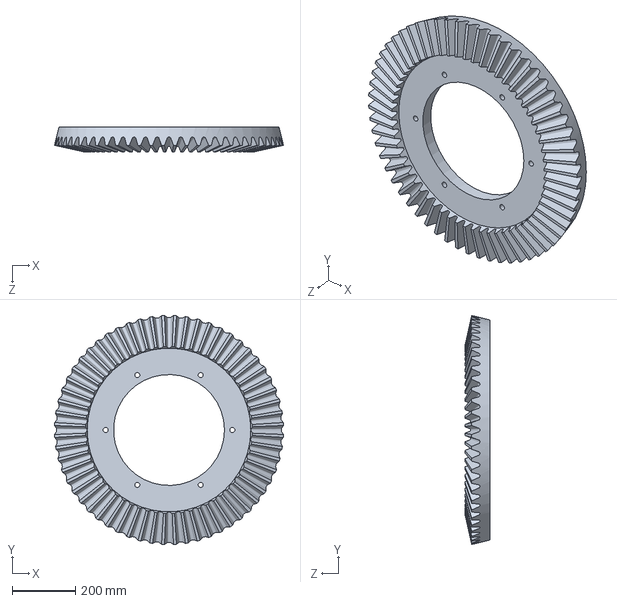
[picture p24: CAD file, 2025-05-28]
CAD/Gears/Gear.SLDPRT
722.8 x 722.8 x 80.4 mm

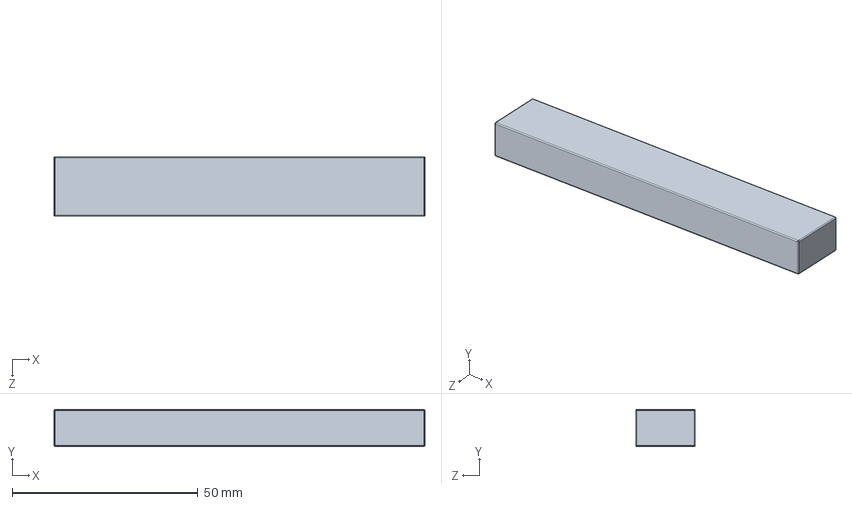
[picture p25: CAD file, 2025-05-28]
CAD/Keys/Gear key.SLDPRT
100.0 x 10.0 x 16.0 mm

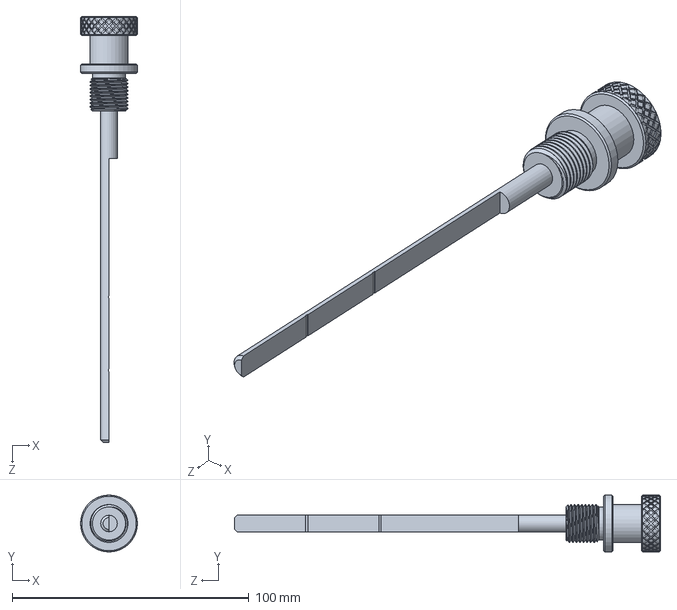
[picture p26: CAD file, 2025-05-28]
CAD/Oil/Oil probe.SLDPRT
24.0 x 24.0 x 180.0 mm

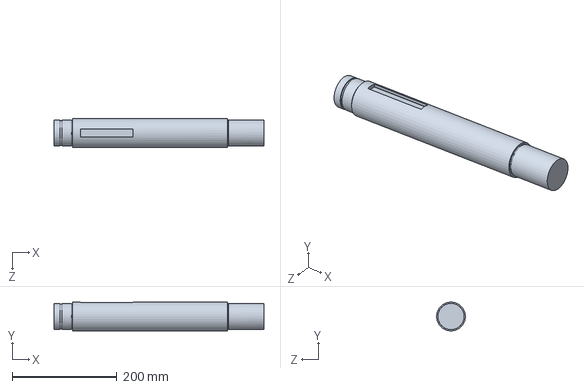
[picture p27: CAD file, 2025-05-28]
CAD/Shafts/Gear shaft.SLDPRT
400.0 x 55.0 x 55.0 mm

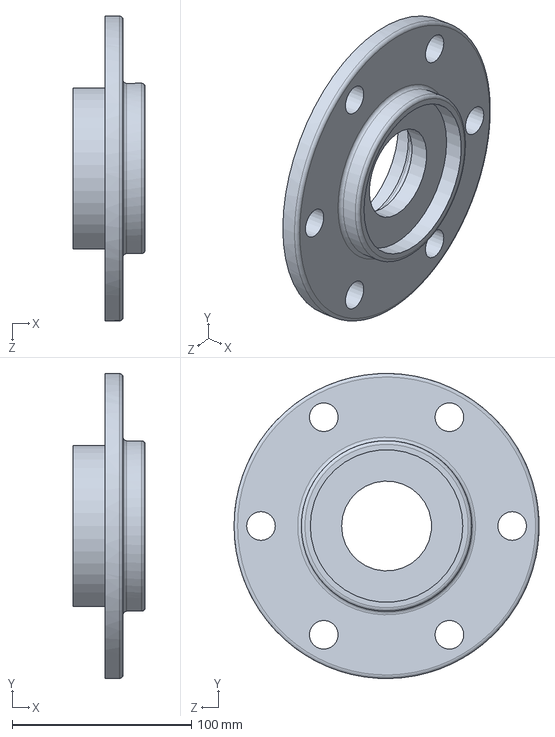
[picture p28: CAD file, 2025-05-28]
CAD/Caps/Cap open.SLDPRT
40.3 x 170.0 x 169.9 mm

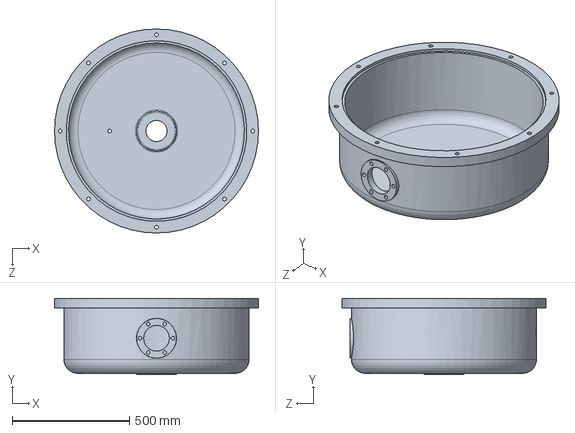
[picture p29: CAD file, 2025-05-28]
CAD/Casing/Big case.SLDPRT
870.0 x 325.0 x 870.0 mm

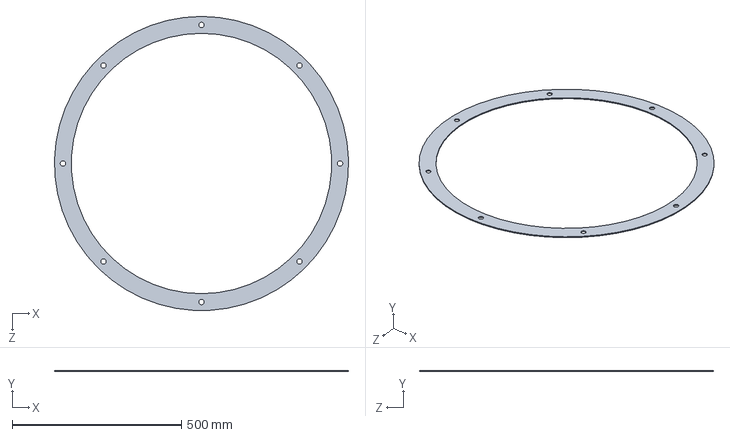
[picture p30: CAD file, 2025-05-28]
CAD/Gaskets/Gasket big case.SLDPRT
869.6 x 3.00 x 870.0 mm

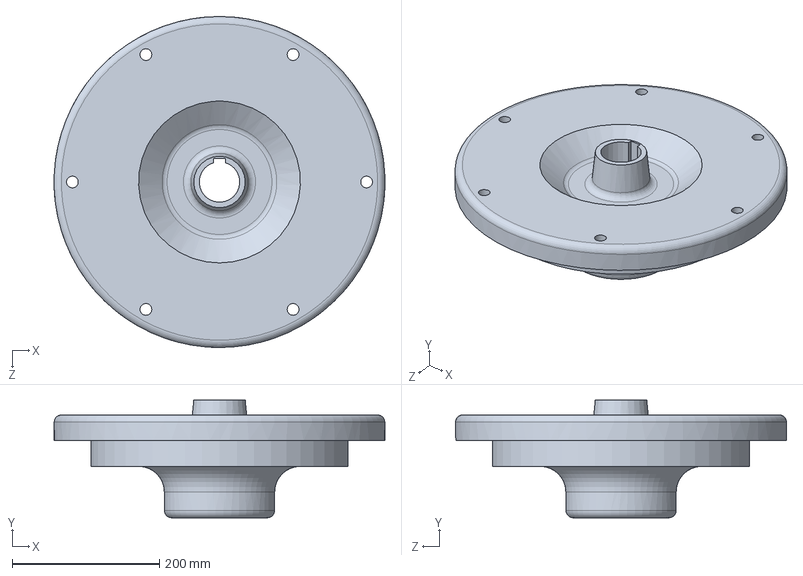
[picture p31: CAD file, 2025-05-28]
CAD/Gears/Gear kit.SLDPRT
449.8 x 160.0 x 450.0 mm

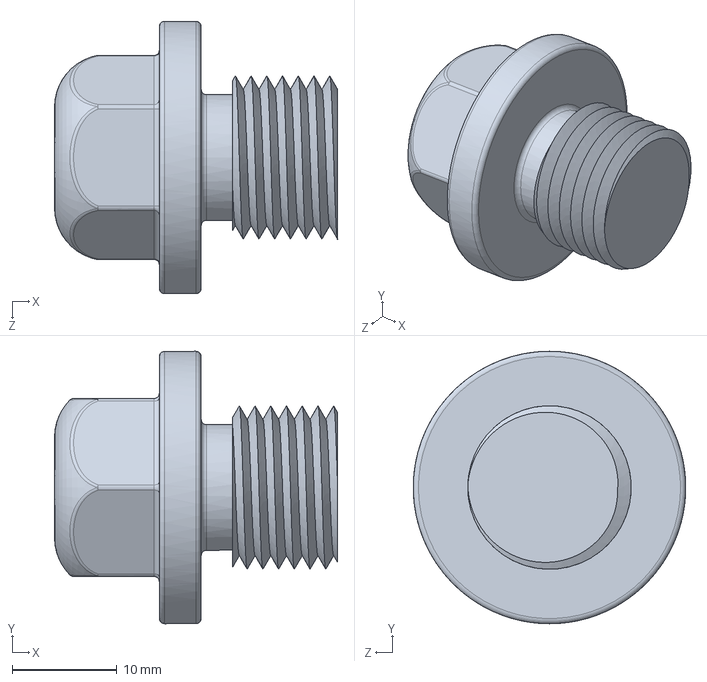
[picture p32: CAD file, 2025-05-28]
CAD/Oil/Oil Plug.SLDPRT
27.0 x 26.0 x 26.0 mm

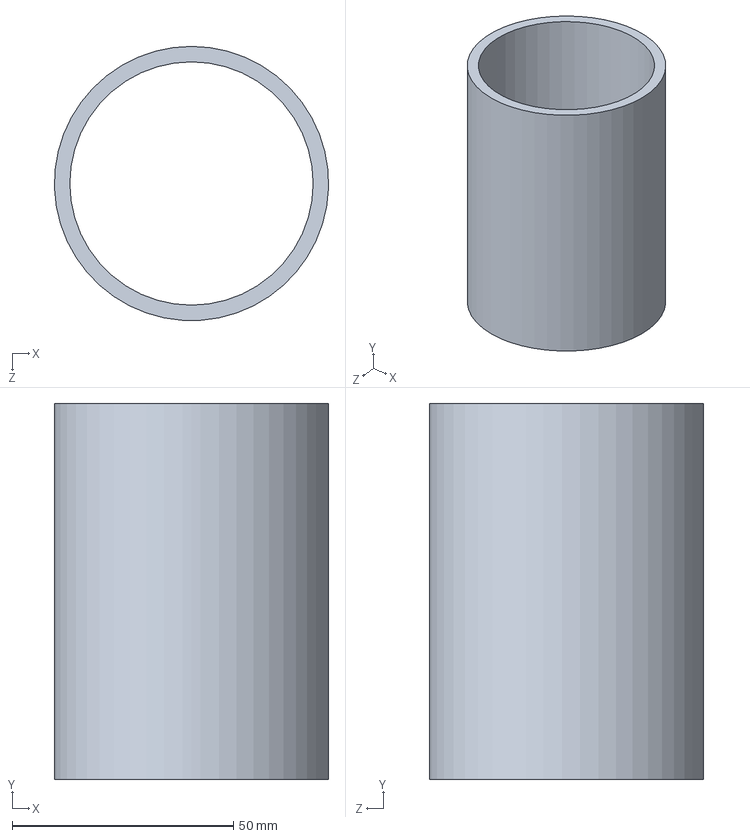
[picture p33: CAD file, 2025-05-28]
CAD/Shafts/Collar.SLDPRT
62.0 x 85.0 x 62.0 mm

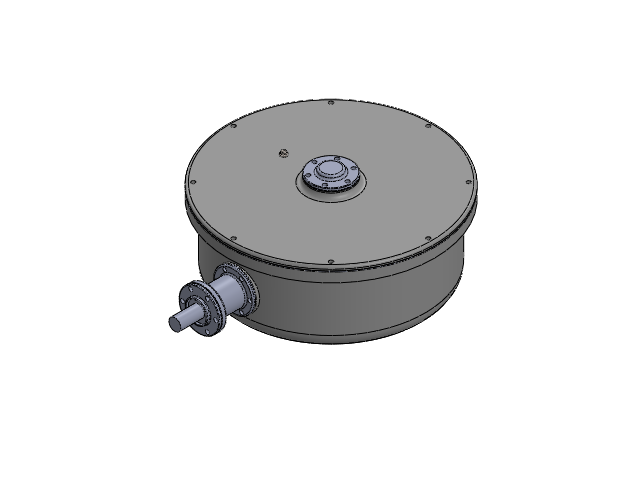
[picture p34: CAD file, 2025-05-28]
CAD/Assembly/Gear box assembly.SLDASM
Big case
small case
Pinion
Gear
Gear shaft
Pinion shaft
Gear kit
radial ball bearing_68_skf x 4
Gear key
Pinion key
Big cap
Cap close
Cap open x 2
TRE20050010 x 2
TRE2005002 x 2
TRE2005004 x 2
Collar
Gasket open cap x 2
Gasket small case
Gasket close cap
Gasket big case
heavy duty external retaining ring_am x 2
Oil Plug x 2

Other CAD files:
CAD/Gears/Assembly.SLDASM
CAD/Sealing/Radial seal.sldasm
CAD/Drawing/DESIGN Drawing.dwg
CAD/Keys/Pinion key.SLDPRT
CAD/Caps/Big cap.SLDPRT
CAD/Gaskets/Gasket open cap.SLDPRT
CAD/Gaskets/Gasket small case.SLDPRT
CAD/Gears/Pinion.SLDPRT
CAD/Sealing/TRE200500-4N011 (0)_0.dwg
CAD/Sealing/TRE20050010.sldprt
CAD/Sealing/TRE2005002.sldprt
CAD/Sealing/TRE2005004.sldprt
CAD/Shafts/Pinion shaft.SLDPRT

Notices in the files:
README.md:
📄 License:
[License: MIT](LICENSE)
